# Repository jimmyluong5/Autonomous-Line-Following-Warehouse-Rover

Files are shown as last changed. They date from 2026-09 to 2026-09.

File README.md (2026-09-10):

# Multi-mode Rover
line_following_github

An autonomous line-following rover built around the **STM32G431KB**, using an 8-channel reflectance sensor array for navigation, UART for diagnostics and control, and ESP-NOW for wireless communication.

The project began as a basic motor-control prototype and has gradually evolved into a full rover platform with autonomous navigation, sensor monitoring, multiple operating modes, and wireless control.
<p align="center">
  
  
  
  
</p>

## Features

* Autonomous line following using an **STM32G431KB**
* 8-channel reflectance sensing using the **QTRX-MD-08A**
* External ADC acquisition using the **MCP3208**
* UART-based control and diagnostics through **PuTTY**
* DC motor control using **FIT0484 motors** and a **TB6612FNG dual motor driver**
* Regulated power distribution using **LM2596 buck converters**
* Wireless communication between two **ESP32-S3** modules using **ESP-NOW**
* Custom 8-bit command packet system for wireless control
* Multiple diagnostic and control modes for testing individual subsystems

## Development Process

### 1. Motor Control

The first stage of the project focused on getting the prototype working.

Two **FIT0484 DC motors** were controlled through a **TB6612FNG dual motor driver**, with the STM32G431KB acting as the main controller.

The power system uses **LM2596 buck converters** to provide regulated voltages to the motors and embedded electronics.

Once reliable bidirectional motor control was established, the prototype was mounted onto a rough cardboard chassis for early testing.

motors_github

### 2. Cardboard Prototype

A temporary cardboard rover was constructed to test the complete prototype before moving to a permanent chassis.

This prototype made it possible to verify

* Motor direction and speed control
* Wheel placement and mechanical alignment
* Breadboard wiring
* Initial sensor placement
* Basic autonomous movement

The prototype successfully demonstrated that the embedded control system and prototype could operate together before the mechanical design was finalized.

first_drive_github

### 3. Reflectance Sensor Integration and UART Sensor Calibration and Diagnostics

The next stage introduced the **QTRX-MD-08A 8-channel reflectance array** for line detection.

The sensor outputs were connected to an external **MCP3208 ADC**, allowing the STM32G431KB to acquire all eight reflectance channels in real time.

Each channel produces an analog voltage corresponding to the reflectivity of the surface underneath the sensor.

During testing

* Higher measured voltage corresponded to darker surfaces
* Lower measured voltage corresponded to lighter surfaces

The STM32 reads the MCP3208 measurements and uses the eight sensor values to determine the rover's position relative to the line.

A UART-based diagnostic interface was also created using **PuTTY** to assist with sensor calibration and subsystem testing.

The interface displays both the measured voltage and raw ADC value for each reflectance channel.

Example output

```text
--- Sensor Test Mode Active ---

CH0: 1.91V | ADC: 2376
CH1: 1.92V | ADC: 2391
CH2: 1.96V | ADC: 2442
CH3: 1.98V | ADC: 2466
CH4: 1.96V | ADC: 2434
CH5: 1.97V | ADC: 2453
CH6: 2.05V | ADC: 2552
CH7: 1.96V | ADC: 2440
```

Testing the array across different surfaces made it possible to determine usable thresholds and calibrate the line-following algorithm.

The UART interface also provides multiple operating and diagnostic modes including

* Servo control
* DC motor testing
* Reflectance voltage monitoring
* Autonomous line-following mode

This made it possible to test individual subsystems without repeatedly modifying the firmware.




### 5. Autonomous Line Following

After calibrating the reflectance sensors, autonomous line following was implemented on the STM32G431KB.

The rover continuously samples all eight channels through the MCP3208 and uses the sensor distribution to determine how far the rover has moved away from the desired path.

Motor commands are then adjusted in real time to steer the rover back toward the line.

This resulted in a complete sensing and control loop

```text
QTRX-MD-08A
      ↓
   MCP3208
      ↓
STM32G431KB
      ↓
Line-Following Logic
      ↓
  TB6612FNG
      ↓
 FIT0484 Motors
```
### 6. CAD Design

After validating the rover's electronics and autonomous navigation on the initial prototype, the mechanical components for the final rover were designed in CAD.

The CAD design focused on creating a rigid and modular platform for the drivetrain, electronics, steering system, and other mechanical components. Designing the rover as an assembly also made it possible to verify component placement, mechanical clearances, and overall dimensions before fabrication.

#### Front Steering Mechanism

The front steering assembly was designed as a separate mechanical system before being integrated into the complete rover. The mechanism allows both front wheels to steer together while maintaining a compact geometry at the front of the chassis.

The assembly was modeled in CAD to verify the movement of the steering components, wheel alignment, and clearance between moving parts.

front_assembly_zoomed

  <i>CAD model demonstrating the rover's front steering assembly.</i>
</p>

#### Main Chassis and Component Layout

The main chassis provides the structural foundation for the rover and supports the motors, wheels, electronics, power system, and cargo platform.

Component placement was considered during the design process to keep the rover compact while maintaining enough space for wiring, assembly, and access to the electrical hardware.

#### Complete Rover Assembly

After designing the individual mechanical components, they were combined into a complete CAD assembly. This allowed the overall rover geometry to be evaluated before the parts were manufactured.

The completed assembly was used to check wheel placement, steering clearance, chassis dimensions, and the positioning of the rover's electrical and mechanical components.

whole car

  <i>Complete CAD assembly of the autonomous warehouse rover.</i>
</p>

The CAD models used for the rover can be found in the [`CAD Models`](./CAD%20Models) directory.

### 7. 3D-Printed Chassis

After validating the electronics and navigation system on the cardboard prototype, the rover was transferred to a custom **3D-printed chassis**.

The chassis provides mounting for

* DC motors
* Wheels
* Breadboard and embedded electronics
* Power system
* Reflectance sensor array
* Additional mechanical components

This provided a much more rigid and repeatable platform for continued development.



### 8. Servo-Based Suspension Testing

After transferring the rover to the 3D-printed chassis, I tested a **servo-actuated front suspension system** using an SG90 servo.

The servo was used to adjust the front of the chassis and verify that the suspension mechanism could move reliably under control from the STM32.

A short demonstration clip is included below.

servo_github

The test helped validate the mechanical design before continuing with wireless control and additional rover integration.

### 9. ESP-NOW Wireless Communication

The current stage of the project focuses on wireless communication between two **ESP32-S3 modules**.

A custom command protocol is being implemented on top of **ESP-NOW**.

Button inputs on the transmitter are active-low. When a button is pressed, the corresponding command bit is set inside an **8-bit command packet**.

```text
Button Input
    ↓
GPIO Read
    ↓
8-Bit Command Packet
    ↓
ESP-NOW Transmission
    ↓
Receiver ESP32-S3
    ↓
Packet Decoding
    ↓
Command Execution
```

esp32_github

The receiving ESP32-S3 unpacks the command byte and executes actions depending on which bits are active.

Initial testing has successfully demonstrated wireless command transmission and execution using LEDs.

### 10. Wireless Button Controller Prototype

After successfully establishing ESP-NOW communication between the two ESP32-S3 modules, I built a physical **button controller prototype** to provide direct wireless input to the rover.

The controller uses an **ESP32-S3** connected to multiple push buttons. Each button represents a different rover command and is read as an active-low GPIO input.

When a button is pressed, the ESP32-S3 updates the corresponding bit in the **8-bit command packet** and transmits the packet wirelessly using ESP-NOW.

The initial controller was assembled on breadboards to allow the button layout, wiring, and firmware to be tested and modified easily.

The prototype successfully demonstrated

* Reliable detection of multiple button inputs
* Active-low GPIO input handling
* Generation of the 8-bit command packet
* ESP-NOW transmission from the handheld controller
* Wireless reception and command decoding on the second ESP32-S3
* LED-based verification of transmitted commands
* Simultaneous handling of multiple command inputs

```text
Push Buttons
     ↓
ESP32-S3 GPIO
     ↓
8-Bit Command Packet
     ↓
   ESP-NOW
     ↓
Receiver ESP32-S3
     ↓
Command Decoding
     ↓
Rover Control
```



This prototype confirms that the wireless controller architecture works as intended and provides a functional input device for the next stage of rover integration.

The next step is to connect the receiver ESP32-S3 to the rover control system so that button commands can directly control functions such as driving, operating modes, and additional rover mechanisms.

#### Current Status Update

Add the following under **Completed**

* Wireless button controller prototype
* 8-bit button command packet transmission
* Multi-button input testing

The wireless controller can now be used as the basis for full manual rover control alongside the autonomous line-following system.

### 11. Bidirectional Serial Monitoring and Wireless Command Debugging

After completing the wireless button controller prototype, I expanded the debugging interface so that both the transmitter and receiver ESP32-S3 modules can display controller activity through their respective serial connections.

On the transmitter side, button presses are detected from the active-low GPIO inputs, encoded into the 8-bit command packet, and displayed through the serial console. This makes it possible to verify that the correct command is being generated before it is transmitted wirelessly.

The packet is then sent over ESP-NOW to the receiver ESP32-S3. The receiver decodes the individual command bits and independently displays the interpreted rover command through its own serial console.

Using PuTTY, I can therefore monitor either side of the wireless connection and verify commands such as

MANUAL MODE
AUTONOMOUS MODE
INCREASING SPEED
DECREASING SPEED
STOP



The controller also supports an 8-bit speed value ranging from 0–255, with the UP and DOWN buttons adjusting the requested rover speed in approximately 5% increments.

Push Buttons
     ↓
     
Transmitter ESP32-S3
     ↓
Button Detection
     ↓
     
Serial Debug Output
     ↓
     
8-Bit Command Packet
     ↓
     
   ESP-NOW
     ↓
     
Receiver ESP32-S3
     ↓
     
Command Decoding
     ↓
     
Serial Debug Output
     ↓
     
MANUAL / AUTO / SPEED / STOP

Having serial output available on both ESP32-S3 modules provides visibility into both sides of the communication system. The transmitter output verifies that controller inputs are being correctly detected and encoded, while the receiver output verifies that the same commands are successfully transmitted, received, and decoded.

This significantly simplifies debugging because communication problems can be isolated to either the controller input stage, ESP-NOW transmission, or receiver-side command decoding.

Adobe Express - IMG_5109

The wireless controller now supports both LED-based command verification and real-time serial debugging, providing a more reliable way to confirm that ESP-NOW packets are being received and interpreted correctly.

### 12. Full Rover Integration & Multi-Subsystem Control

With the 3D-printed chassis, power distribution, and core firmware validated, the rover has progressed to a **fully integrated, multi-mode platform**. All critical subsystems are now orchestrated directly by the STM32G431KB state machine:

* **Integrated Steering & Suspension**: The front servo suspension and steering mechanism is directly integrated into the drive loop, enforcing calibrated limits (45° to 135°) with dedicated combined driving modes (front active steering + rear differential motor thrust).
* **Unified UART Telemetry & Diagnostic Interface**: An interactive, non-blocking serial dashboard allows on-the-fly mode switching between:
  * `[m]` Motor Control Mode (Differential Drive)
  * `[c]` Combined Control System (Active Steering + Rear Motors)
  * `[a]` Autonomous PID Line Following
  * `[s]` Steering Servo Calibration (45°–135°)
  * `[t]` Stepper Motor Positioning
  * `[p]` Piezo Speaker / Buzzer Frequency Testing
  * `[v]` / `[n]` Real-Time ADC Reflectance & Surface Classification

### 13. Custom ESP32-S3 Wireless Handheld Controller & Real-Time Telemetry Dashboard



The communication architecture establishes a complete, closed-loop bidirectional data link between the handheld transmitter controller, the on-rover ESP32-S3 receiver, and the main **STM32G431KB** robot brain:

```text
+------------------------------------+             +----------------------------------+             +----------------------------------+
|    Handheld ESP32-S3 Transmitter   |             |     Rover ESP32-S3 Receiver      |             |       STM32G431KB Robot MCU      |
|                                    |   ESP-NOW   |                                  |    UART1    |                                  |
| - Analog Joystick (ADC1)           | ----------> | - Decodes ESP-NOW data_packet_t  | ----------> | - LPUART1 RX (PA3): 0xAA + packet|
| - 5-Way Button Matrix (Mode/Speed) |   (2.4GHz)  | - Forwards 0xAA + packet via TX  |  (Pin 42)   | - Drives TB6612FNG Dual Motors   |
|                                    |             |                                  |             |                                  |
| - 2.4" ILI9341 Diagnostics Display | <---------- | - Forwards robot_status_t via TX | <---------- | - LPUART1 TX (PA2): 0xBB + status|
|   (Live Speeds, Ticks, RTOS stats) |   ESP-NOW   | - Captures 0xBB + status via RX  |  (Pin 2)    | - DWT Timer Benchmarks & Metrics |
+------------------------------------+             +----------------------------------+             +----------------------------------+
```

### 14. Inter-MCU UART Bridge & Hardware Verification (ESP32-S3 <-> STM32G431KB)

To complete the end-to-end communication pipeline, dedicated hardware UART communication was established and verified between the rover's on-board **ESP32-S3 Receiver** and the **STM32G431KB** microcontroller:

* **Hardware Pinout**:
  * **ESP32-S3 Pin 42 (UART1 TX)** --> **STM32 PA10 (USART1 RX / D1)** @ 115,200 baud
  * **ESP32-S3 Pin 2 (UART1 RX)** <-- **STM32 PA9 (USART1 TX / D0)** @ 115,200 baud
  * **ST-Link Debug Console**: **STM32 PA2 (TX) / PA3 (RX)** via LPUART1 @ 115,200 baud (keeps PuTTY console communication completely isolated from rover control traffic).
  * **Common Ground (GND)** connected across all modules with regulated 5V buck power distribution.

### 15. Real-Time Proportional Manual Control & Closed-Loop Wireless Driving

The manual driving implementation provides responsive, proportional throttle and differential steering mapped directly from the analog 2D joystick on the handheld controller to the rover's TB6612FNG motor driver:

* **Joystick Mixing & Proportional Control**:
  * Filtered joystick X/Y coordinates from SAR ADC1 are converted into differential drive PWM duty cycles (`0%` to `100%`) for smooth acceleration, reverse, and spot-turning.
  * Real-time deadband filtering ($\pm 25$ ADC counts) prevents unintended motor creep when the spring-centered joystick is resting at neutral.
* **Safety Watchdog & Inactivity Alarm**:
  * An integrated 5-second inactivity watchdog trips into fail-safe mode if wireless packets or user input stall, sounding an audible 8-beep alarm pattern on the piezo buzzer and automatically disarming the motors.
* **Live Return Diagnostics**:
  * The STM32 sends back 20 Hz binary telemetry frames (`0xAA + robot_status_t`) carrying live DWT superloop metrics (CPU load, latency, jitter, loop frequency) and link quality parameters directly overlaid on the 2.4" TFT LCD.

<p align="center">
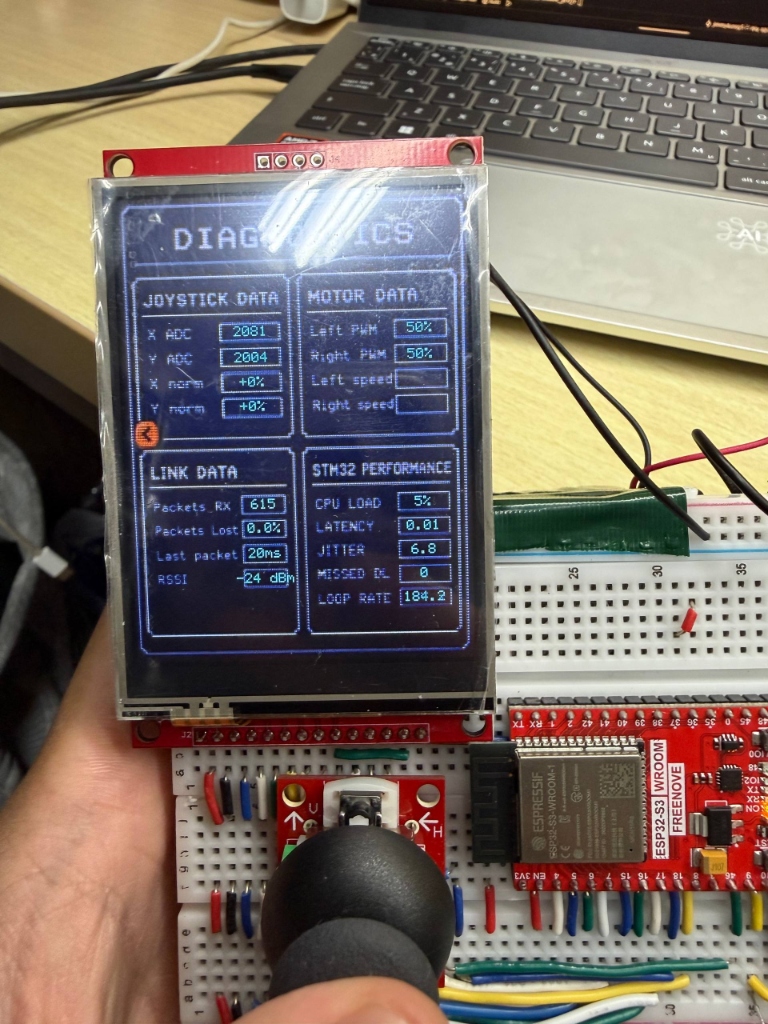
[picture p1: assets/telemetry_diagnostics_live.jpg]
Live 4-Quadrant Diagnostic Dashboard on Handheld Controller
  
  <br>
  <i>Handheld 2.4" TFT LCD displaying real-time 4-quadrant diagnostics: Live Joystick coordinates, Differential Motor PWM, ESP-NOW Link Quality, and STM32 Superloop Performance.</i>
</p>

<p align="center">
  <!-- Manual Driving Demonstration GIF -->
  Manual Rover Driving Demonstration
  <br>
  <i>Live demonstration: Real-time proportional manual joystick control and responsive wireless maneuvering.</i>
</p>

https://github.com/user-attachments/assets/510c7fbb-fd98-4aba-af33-ecc1c66d9171

## Hardware Interconnect (Receiver <-> STM32):
* **ESP32-S3 Pin 42 (UART1 TX)** --> **STM32 PA10 (USART1 RX / D1)** @ 115,200 baud
* **ESP32-S3 Pin 2 (UART1 RX)** <-- **STM32 PA9 (USART1 TX / D0)** @ 115,200 baud
* **ST-Link Debug Console**: **STM32 PA2 (TX) / PA3 (RX)** via LPUART1 @ 115,200 baud
* **Common Ground (GND)** connected across all modules with regulated 5V buck power distribution.

#### Packet Protocols:
1. **Control Packet (`0xAA + data_packet_t`)**: Transmitted at 40 Hz from transmitter to STM32, containing 5-bit tactile button masks, commanded speed (`0-255`), 12-bit analog joystick X/Y deflections, and operating mode (`Manual`, `Autonomous`, `IMU`).
2. **Telemetry Packet (`0xAA + robot_status_t`)**: Transmitted at 20 Hz from STM32 back to transmitter, delivering real-time CPU load percentage, loop rate (Hz), execution latency (ms), jitter (ms), and missed deadline counters to the controller's diagnostic UI.

To provide manual override, multi-mode switching, and live diagnostics for the rover, a dedicated handheld wireless controller was developed using a dual-core **ESP32-S3** (240 MHz) and a 2.4-inch **ILI9341 SPI TFT LCD (240×320)**.

The controller provides an interactive graphical user interface (GUI), live telemetry monitoring, and low-latency packet transmission over **ESP-NOW**.

#### 1. Hardware Architecture & Inputs
* **Microcontroller**: Freenove ESP32-S3 WROOM (16MB Flash, 8MB PSRAM, Dual Xtensa LX7 cores running at 240 MHz).
* **Display & Touch**: 2.4" 240×320 SPI LCD driven by an ILI9341 controller, sharing the SPI bus with an XPT2046 resistive touch controller.
* **Analog 2D Joystick**: Multi-sampled through SAR ADC1 (GPIO 4 and GPIO 5) with 16× oversampling, software deadband filtering, and axis normalization.
* **5-Way Tactile Button Matrix**: Multi-button input array with two-stage temporal debouncing for menu navigation, speed adjustments, and emergency stop.
* **Audio Feedback**: PWM buzzer generating audible confirmation tones on button interactions and a 5-second inactivity watchdog alarm.

```text
[ Analog Joystick (ADC1) ] ──┐
[ 5-Button Matrix (GPIO) ] ──┼──> [ ESP32-S3#1 Controller & Transmitter ] ──(ESP-NOW 2.4GHz)──> [ESP32#2 Rover Receiver ] ──(USART1 PA9/PA10)──> [ STM32G431KB ]
[ Piezo Speaker (LEDC)   ] ──┤      │ (FreeRTOS Core 0/1)                                                                                         │
[ ILI9341 240x320 LCD    ] ──┘      └──<── Live 4-Quadrant Diagnostic Telemetry Return <──────────────────────────────────────────────────────────┘
```

#### 2. Embedded Graphics Engine & Menu Animation
* **High-Speed JPEG Decoder (`tjpgd`)**: Decompresses embedded full-color JPEG assets directly from Flash memory into DMA-accessible RAM.
* **Ping-Pong SPI DMA Buffering**: Uses dual parallel line buffers to pipeline SPI transfers asynchronously while computing the next scanline on the CPU.
* **Main Menu UI**: Plays a 15-frame animated rover sequence with an active pulsing yellow hover cursor to select operating modes (**Manual Mode**, **Autonomous Mode**, **IMU Mode**).
* **Showcase Pages**: Dedicated QR code and documentation screens for GitHub and LinkedIn.

#### 3. Real-Time Manual Dashboard & 4-Quadrant Diagnostics
When entering **Manual Mode**, the controller renders an industrial diagnostic dashboard with live telemetry overlays across four dedicated quadrants:

1. **Quadrant 1: Joystick Data (Top Left)**:
   * **X / Y ADC**: 12-bit raw analog reading from SAR ADC1 (`0–4095`).
   * **X / Y norm**: Normalized deflection percentage (`-100%` to `+100%`) with center deadband filtering.
2. **Quadrant 2: Motor Data (Top Right)**:
   * **Left / Right PWM**: Real-time commanded throttle percentage dispatched to the TB6612FNG H-bridge drivers.
   * **Steering / Differential Drive**: Proportional steering mixing turning commands cleanly into left and right wheel speeds.
3. **Quadrant 3: Link Data (Bottom Left)**:
   * **Packets RX**: Total return telemetry frames successfully received.
   * **Packets Lost**: Real-time ESP-NOW packet drop rate (`0.0%`).
   * **Last packet**: Inter-packet arrival latency (`20 ms`).
   * **RSSI**: Receiver signal strength indicator in dBm (`-24 dBm`).
4. **Quadrant 4: STM32 Performance (Bottom Right)**:
   * **CPU Load**: Real-time superloop CPU utilization percentage measured by hardware DWT cycle counting.
   * **Latency**: Active loop execution latency measured to 0.01 ms precision.
   * **Jitter**: RFC 3550 exponential moving average loop jitter filter.
   * **Missed DL**: Missed loop deadline counter (execution taking >10 ms).
   * **Loop Rate**: Deterministic superloop update frequency (~184 Hz).

#### 4. Real-Time System Performance & RTOS Telemetry
To benchmark control loop determinism (comparing FreeRTOS preemptive multitasking vs bare-metal superloops), a dedicated telemetry module (`metrics.c` on ESP32 & `uart_control.c` on STM32) tracks real-time performance indicators:

| Telemetry Metric | Measurement Method | Typical Reading | Purpose |
| :--- | :--- | :--- | :--- |
| **CPU Load** | Active computation vs superloop budget | `~5–8%` | Verifies compute headroom |
| **Latency** | ARM Cortex-M4 DWT Cycle Counter (`CYCCNT`) | `0.01–0.05 ms` | Measures microcontroller active compute latency |
| **Jitter** | RFC 3550 Exponential Moving Average filter | `1.5–6.8 ms` | Tracks loop timing stability |
| **Missed DL** | Execution time exceeding 10 ms budget | `0` | Proves hard real-time scheduling guarantees |
| **Loop Rate** | Hardware period reciprocal (`1 / dt`) | `~100–185 Hz` | Confirms responsive control execution |
| **Link RSSI** | ESP-NOW WiFi MAC RX Control Metadata | `-24 to -48 dBm` | Verifies wireless link budget and antenna range |

#### 5. Wireless Communication Protocol (`ESP-NOW`) & Safety Watchdog
Control packets (`data_packet_t`) are packed into a compact binary structure and transmitted as 2.4 GHz peer-to-peer unicast packets to the receiver ESP32 on the rover:
```c
typedef struct __attribute__((packed)) {
    uint8_t  button_data;  // 5-bit tactile button mask
    uint8_t  speed;        // Commanded throttle (0–255)
    uint16_t joystick_x;   // Filtered X analog deflection
    uint16_t joystick_y;   // Filtered Y analog deflection
    uint8_t  imu_x;        // Reserved for IMU tilt control
    uint8_t  imu_y;        // Reserved for IMU tilt control
    uint8_t  mode;         // Active operating mode
} data_packet_t;
```

* **5-Second Inactivity Fail-Safe**: If no user input or joystick deflection is detected for 5 seconds in Manual Mode, the transmitter automatically triggers an audible buzzer alarm pattern (`speaker_pattern(8, 75, 75)`), trips the fail-safe state, cuts motor drive output to neutral stop, and returns safely to the main menu.

## Hardware

| Component | Purpose |
| --- | --- |
| STM32G431KB | Main rover controller |
| QTRX-MD-08A | 8-channel reflectance sensor array |
| MCP3208 | External ADC for reflectance measurements |
| FIT0484 | DC drive motors |
| TB6612FNG | Dual DC motor driver |
| ESP32-S3 ×3 | Wireless transmitter and receiver |
| LM2596 | Buck converters for voltage regulation |
| SG90 Servo | Mechanical actuation |
| LADDA Batteries | Main power source |

## Software and Communication

* Embedded C
* STM32 firmware
* UART
* SPI
* ESP-NOW
* PuTTY
* 8-bit command packet protocol

## Roadmap & Next Steps

```text
Current: Full Rover + UART Telemetry
                ↓
Phase 1: ESP32-to-STM32 Bridge & Wireless Joystick Control
                ↓
Phase 2: IMU Orientation & Heading Stabilization
                ↓
Phase 3: Time-of-Flight (ToF) Collision Detection & Auto-Braking
```

### Phase 1: ESP32-to-STM32 Bridge & Wireless Joystick Controller
* **Inter-MCU Communication**: Bridge the receiver ESP32-S3 directly to the STM32G431KB via hardware UART, forwarding decoded wireless packets into real-time drive and mode commands.
* **Analog Joystick Transmitter**: Upgrade the handheld controller with a 2-axis analog joystick to provide smooth, continuous proportional throttle and steering rather than discrete button presses.

### Phase 2: IMU Integration & Dynamic Heading Stabilization
* Integrate a 6-DOF / 9-DOF **Inertial Measurement Unit (IMU)** via I2C/SPI on the STM32.
* Implement closed-loop attitude estimation and yaw-rate compensation to maintain straight-line tracking, prevent drift, and detect chassis tilt over uneven terrain.

### Phase 3: Time-of-Flight (ToF) Collision Detection
* Integrate forward-facing **Time-of-Flight (ToF) distance sensors** (e.g., VL53L0X / VL53L1X).
* Implement real-time proximity sensing with dynamic speed reduction and autonomous emergency braking (AEB) to avoid obstacles during both manual and autonomous line-following modes.

## Current Status Summary

### Completed
- [x] Bidirectional DC motor control with TB6612FNG & dual hardware PWM (TIM1_CH1 / TIM17_CH1)
- [x] 8-Channel reflectance array acquisition via MCP3208 SPI ADC
- [x] Autonomous line-following navigation with PID control
- [x] 3D-printed chassis assembly and mechanical integration
- [x] Servo-actuated steering & suspension control (45 deg - 135 deg limits)
- [x] Multi-subsystem UART diagnostic & control dashboard
- [x] Dual ESP32-S3 ESP-NOW wireless link with binary command packet protocol (40 Hz)
- [x] Dedicated dual UART routing on STM32 (USART1 on PA9/PA10 for ESP32 receiver, LPUART1 on PA2/PA3 for PC PuTTY console)
- [x] Handheld wireless controller with 2.4" 240x320 ILI9341 LCD, 2D joystick grid, and 4 diagnostic telemetry quadrants
- [x] Real-time proportional manual joystick driving with differential throttle mixing
- [x] 5-second inactivity fail-safe timeout watchdog with multi-tone audio alarm
- [x] Closed-loop STM32 DWT performance metrics & link telemetry transmission over ESP-NOW back to handheld transmitter LCD (20 Hz)

### In Progress
- [ ] IMU sensor integration & dynamic heading stabilization (LSM6DS3 6-DoF accelerometer + gyroscope)

### Planned
- [ ] IMU-based closed-loop straight-line heading stabilization & tilt compensation
- [ ] Time-of-Flight (ToF) sensor integration for forward collision avoidance & emergency braking
- [ ] Follow-me feature using the FireBeetle 2 Board ESP32-S3 (N16R8) AIoT Microcontroller with Camera
- [ ] Return to Home Feature using dual IMUs (Adafruit LSM6DS3TR-C & MPU-6050)

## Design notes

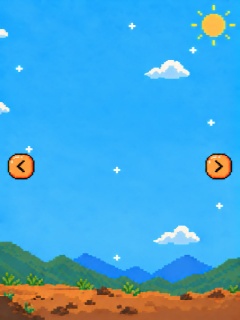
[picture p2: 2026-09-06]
esp32_transmitter/src/images/leftright.jpg

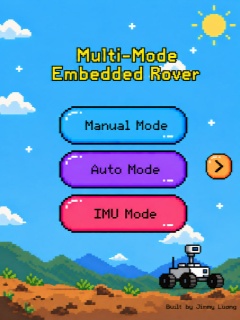
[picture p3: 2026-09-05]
esp32_transmitter/src/images/frame8.jpg

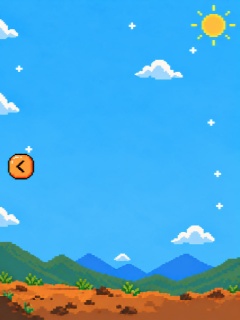
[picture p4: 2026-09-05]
esp32_transmitter/src/images/leftbasic.jpg

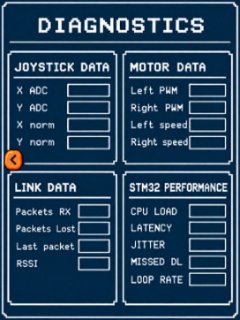
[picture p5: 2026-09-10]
esp32_transmitter/src/images/secondpagedata.jpg

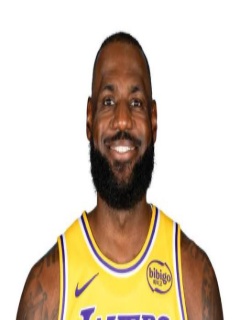
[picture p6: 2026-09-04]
esp32_transmitter/src/images/lebron.jpg

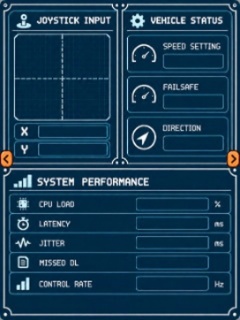
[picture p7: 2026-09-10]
esp32_transmitter/src/images/blankfirstpage.jpg

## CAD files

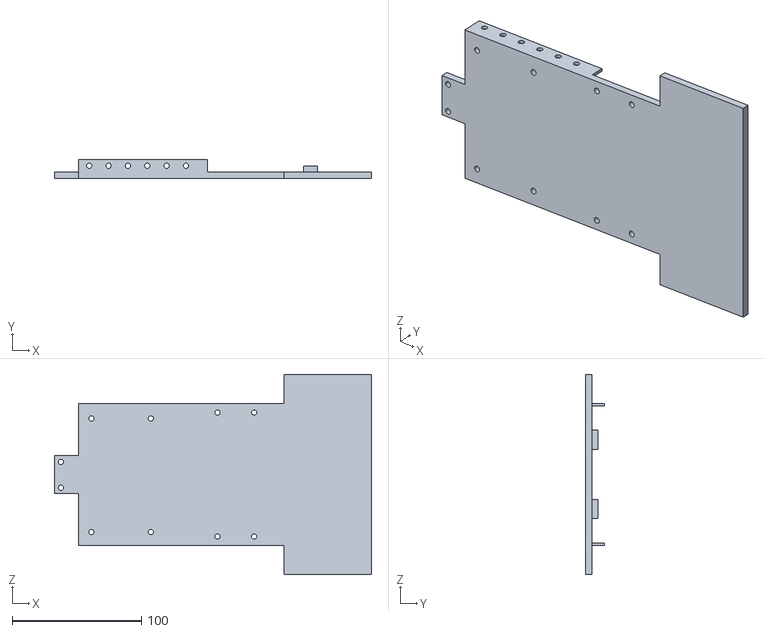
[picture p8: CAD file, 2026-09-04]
CAD Models/STL for back/main chassis-(1).STL
245.6 x 15.0 x 155.0

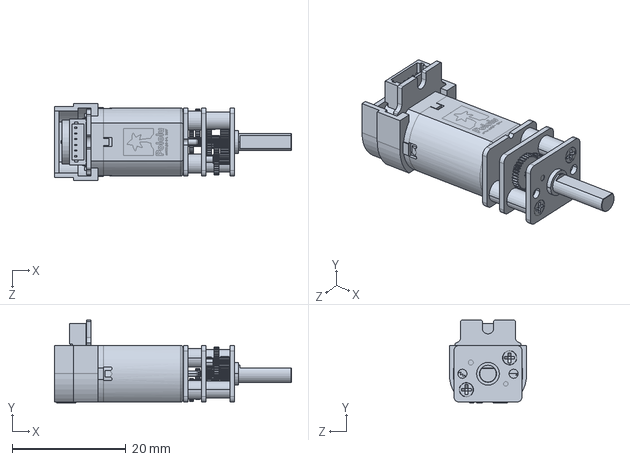
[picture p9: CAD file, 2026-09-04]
CAD Models/DC motor.SLDPRT
41.6 x 14.5 x 13.6 mm

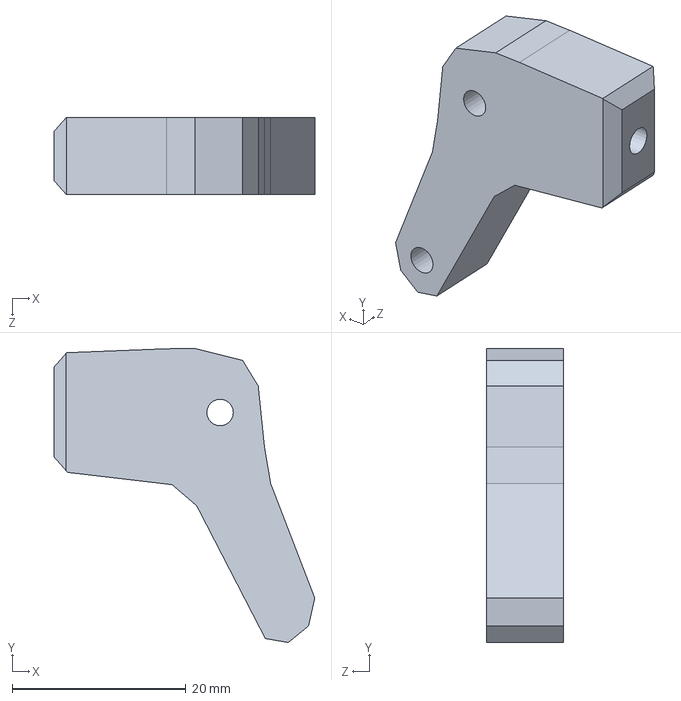
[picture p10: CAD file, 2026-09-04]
CAD Models/Front steering/L arm mirrored.SLDPRT
30.0 x 33.8 x 8.86 mm

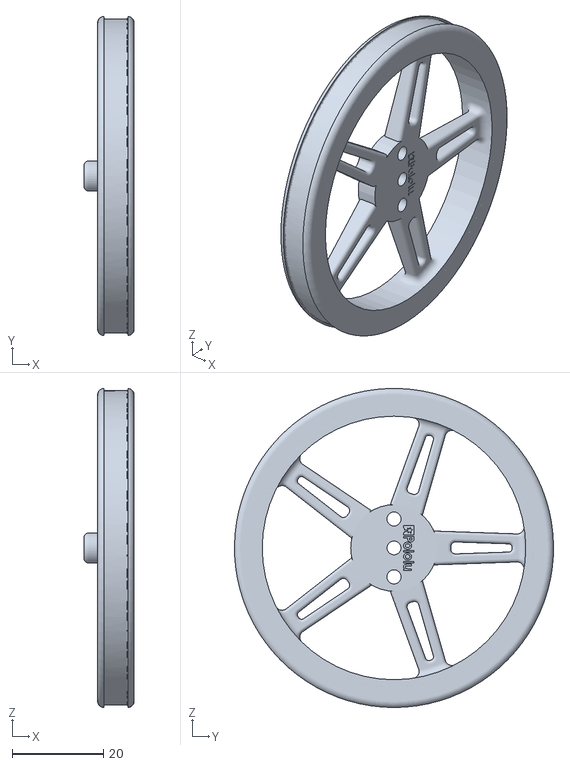
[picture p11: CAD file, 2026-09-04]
CAD Models/Front steering/STL files for front/front wheels-(2).STL
11.0 x 70.0 x 70.0

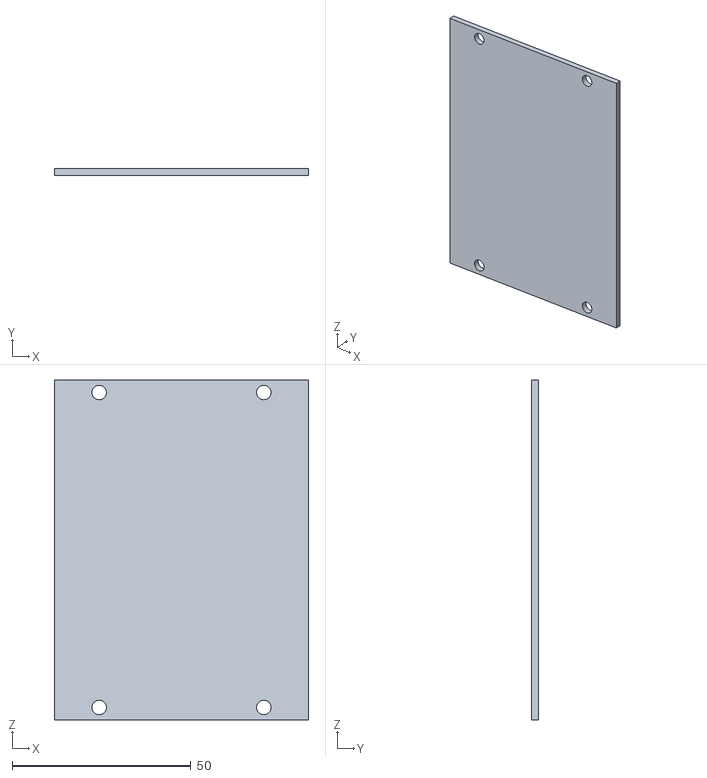
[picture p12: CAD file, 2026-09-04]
CAD Models/STL for back/sensor platform-(1).STL
71.0 x 2.00 x 95.0

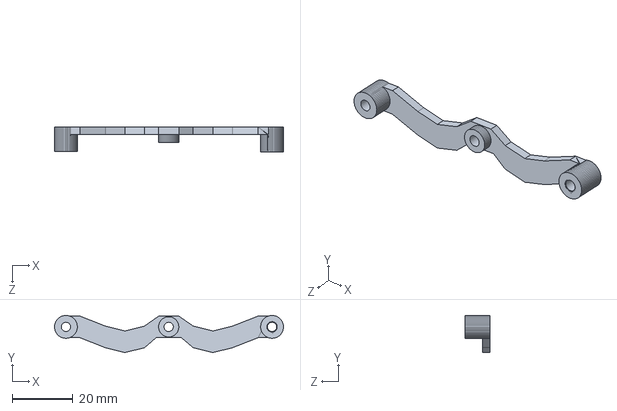
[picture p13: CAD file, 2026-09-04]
CAD Models/Front steering/linkage.SLDPRT
75.2 x 12.2 x 8.18 mm

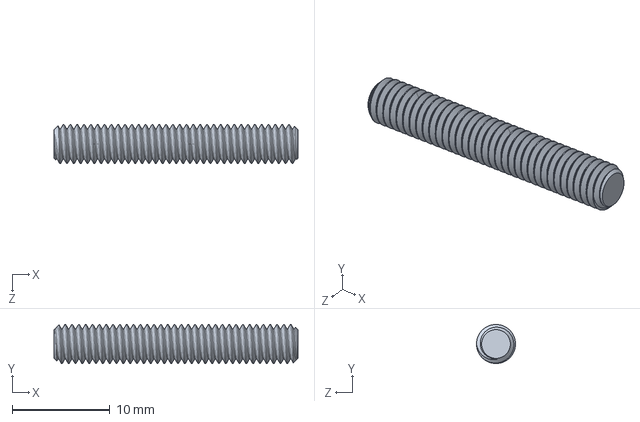
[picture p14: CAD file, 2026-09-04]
CAD Models/4x25 mm threaded rod.SLDPRT
25.0 x 4.00 x 4.00 mm

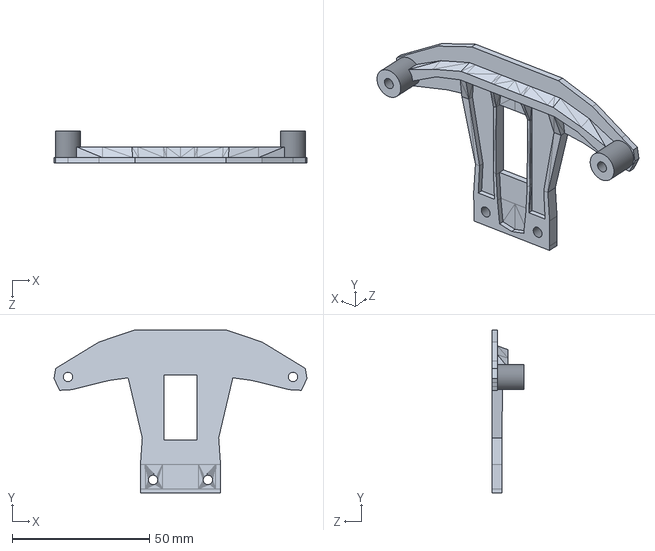
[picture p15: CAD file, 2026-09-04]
CAD Models/Front steering/Part4.SLDPRT
92.2 x 59.4 x 11.7 mm

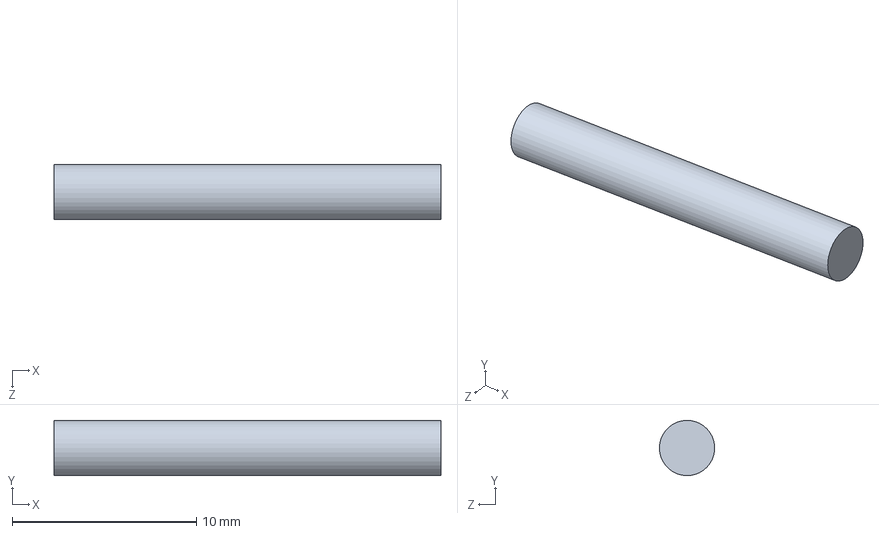
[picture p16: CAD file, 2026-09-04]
CAD Models/Front steering/21 mm rod.SLDPRT
21.0 x 3.00 x 2.99 mm

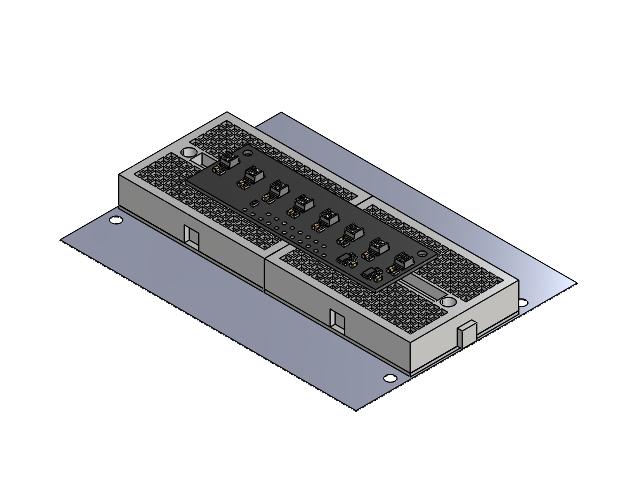
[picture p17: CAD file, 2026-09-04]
CAD Models/sensor assembly.SLDASM
ir sensor
mini breadboard x 2

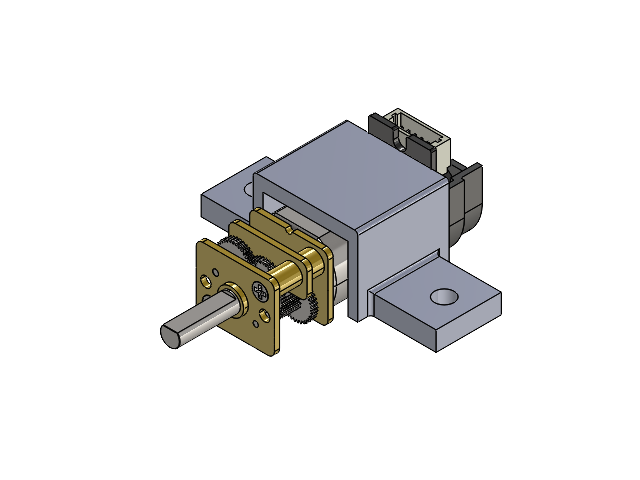
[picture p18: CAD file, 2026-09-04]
CAD Models/DC motor assembly.SLDASM
DC motor mount
DC motor

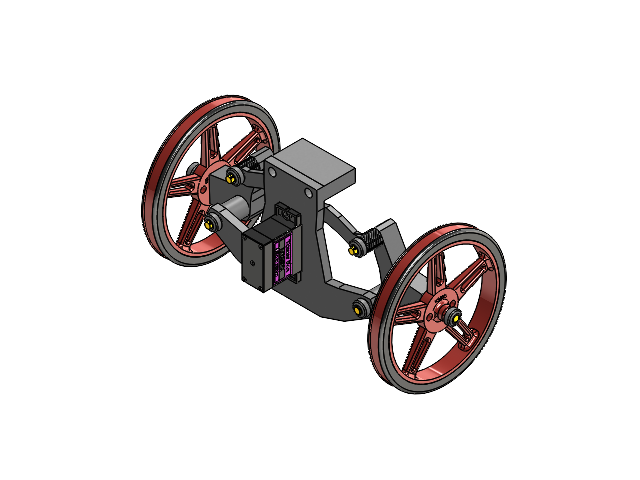
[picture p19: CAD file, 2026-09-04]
CAD Models/Front steering/front assembly.SLDASM
Tower Pro MG90S Micro servo
linkage
L arm mirrored
L arm
front wheels x 2
wheel axle x 8
Front Chassis
25 mm rod x 2
21 mm rod x 2
32 mm rod x 2
servo horn unidirectional

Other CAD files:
CAD Models/main chassis.SLDPRT
CAD Models/Front steering/STL files for front/linkage-(1).STL
CAD Models/Front steering/STL files for front/Left arm-(1).STL
CAD Models/STL for back/rear wheel-(2).STL
CAD Models/Front steering/STL files for front/right arm-(1).STL
CAD Models/sensor platform.SLDPRT
CAD Models/4x40 mm threaded rod.SLDPRT
CAD Models/7.6 cm wheel.SLDPRT
CAD Models/830 Tie Breadboard.SLDPRT
CAD Models/DC motor mount.SLDPRT
CAD Models/Front steering/25 mm rod.SLDPRT
CAD Models/Front steering/32 mm rod.SLDPRT
CAD Models/Front steering/Front Chassis.SLDPRT
CAD Models/Front steering/L arm.SLDPRT
CAD Models/Front steering/STL files for front/Front Chassis-(1).STL
CAD Models/Front steering/STL files for front/servo horn-(1).STL
CAD Models/Front steering/Tower Pro MG90S Micro servo.SLDPRT
CAD Models/Front steering/front wheels.SLDPRT
CAD Models/Front steering/servo horn.SLDPRT
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

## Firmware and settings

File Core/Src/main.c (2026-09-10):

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
/* Includes ------------------------------------------------------------------*/
#include "main.h"

/* USER CODE BEGIN Includes */
#include <motor.h>
#include <robot.h>
#include <servo.h>
//#include <stepper.h>
#include <string.h>
#include <uart_control.h>
#include "LSM6DS3.h"


/* USER CODE END Includes */


COM_InitTypeDef BspCOMInit;

SPI_HandleTypeDef hspi1;

TIM_HandleTypeDef htim1;
TIM_HandleTypeDef htim3;
TIM_HandleTypeDef htim16;
TIM_HandleTypeDef htim17;

UART_HandleTypeDef huart1;

/* USER CODE BEGIN PV */
UART_HandleTypeDef huart2;
/* USER CODE END PV */

void SystemClock_Config(void);
static void MX_GPIO_Init(void);
static void MX_TIM17_Init(void);
static void MX_SPI1_Init(void);
static void MX_TIM16_Init(void);
static void MX_TIM3_Init(void);
static void MX_TIM1_Init(void);
static void MX_USART1_UART_Init(void);
/**
  * @brief  The application entry point.
  * @retval int
  */
int main(void)
{

  /* MCU Configuration--------------------------------------------------------*/

  /* Reset of all peripherals, Initializes the Flash interface and the Systick. */
  HAL_Init();

  /* Configure the system clock */
  SystemClock_Config();

  /* Initialize all configured peripherals */
  MX_GPIO_Init();
  MX_TIM17_Init();
  MX_SPI1_Init();
  MX_TIM16_Init();
  MX_TIM3_Init();
  MX_TIM1_Init();
  MX_USART1_UART_Init();
  /* USER CODE BEGIN 2 */
  Robot_Init(); //this calls motor_init.
  servo_init();
  //stepper_init();
  DWT_Init();

  /* USER CODE END 2 */

  /* Initialize leds */
  BSP_LED_Init(LED_GREEN);

  /* Initialize COM1 port (115200, 8 bits (7-bit data + 1 stop bit), no parity */
  BspCOMInit.BaudRate   = 115200;
  BspCOMInit.WordLength = COM_WORDLENGTH_8B;
  BspCOMInit.StopBits   = COM_STOPBITS_1;
  BspCOMInit.Parity     = COM_PARITY_NONE;
  BspCOMInit.HwFlowCtl  = COM_HWCONTROL_NONE;
  if (BSP_COM_Init(COM1, &BspCOMInit) != BSP_ERROR_NONE)
  {
    Error_Handler();
  }
  huart2 = hcom_uart[COM1];
  UART_CONTROL_init();

  /* Infinite loop */
  /* USER CODE BEGIN WHILE */
  while (1) {
    uint32_t loop_start_us = DWT_GetMicros();
    Telemetry_Loop_Start();

    UART_CONTROL_update();
    UART_CONTROL_check_timeout();
    Robot_Update();
    Servo_Update();

    Telemetry_Loop_End(loop_start_us);

    static uint32_t last_telemetry_time = 0;
    if ((HAL_GetTick() - last_telemetry_time) >= 50) {
      last_telemetry_time = HAL_GetTick();
      UART_Send_Telemetry();
    }
    /* USER CODE END WHILE */

    /* USER CODE BEGIN 3 */
  }
  /* USER CODE END 3 */
}

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
/* USER CODE BEGIN Header */
/**
 ******************************************************************************
 * @file           : main.c
 * @brief          : Main program body
 ******************************************************************************
 * @attention
 *
 * Copyright (c) 2026 STMicroelectronics.
 * All rights reserved.
 *
 * This software is licensed under terms that can be found in the LICENSE file
 * in the root directory of this software component.
 * If no LICENSE file comes with this software, it is provided AS-IS.
 *
 ******************************************************************************
 */
/* USER CODE END Header */

/**
  * @}
  */

/**
  * @}
  */

/**
  * @brief  This function is executed in case of error occurrence.
  * @retval None
  */
void Error_Handler(void)
{
  /* USER CODE BEGIN Error_Handler_Debug */
  /* User can add his own implementation to report the HAL error return state */
  __disable_irq();
  __HAL_RCC_GPIOB_CLK_ENABLE();
  GPIO_InitTypeDef GPIO_InitStruct = {0};
  GPIO_InitStruct.Pin = LED2_PIN;
  GPIO_InitStruct.Mode = GPIO_MODE_OUTPUT_PP;
  GPIO_InitStruct.Pull = GPIO_NOPULL;
  GPIO_InitStruct.Speed = GPIO_SPEED_FREQ_LOW;
  HAL_GPIO_Init(LED2_GPIO_PORT, &GPIO_InitStruct);

  while (1) {
    HAL_GPIO_TogglePin(LED2_GPIO_PORT, LED2_PIN);
    for (volatile uint32_t i = 0; i < 500000; i++)
      ;
  }
  /* USER CODE END Error_Handler_Debug */
}
#ifdef USE_FULL_ASSERT
/**
  * @brief  Reports the name of the source file and the source line number
  *         where the assert_param error has occurred.
  * @param  file: pointer to the source file name
  * @param  line: assert_param error line source number
  * @retval None
  */
void assert_failed(uint8_t *file, uint32_t line)
{
  /* USER CODE BEGIN 6 */
  /* User can add his own implementation to report the file name and line
     number, ex: printf("Wrong parameters value: file %s on line %d\r\n", file,
     line) */
  /* USER CODE END 6 */
}
#endif /* USE_FULL_ASSERT */

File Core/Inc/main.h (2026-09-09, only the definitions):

#define DC_Motor_BIN2_Pin GPIO_PIN_0
#define DC_Motor_BIN2_GPIO_Port GPIOA
#define DC_Motor_BIN1_Pin GPIO_PIN_1
#define DC_Motor_BIN1_GPIO_Port GPIOA
#define DC_Motor_STBY_Pin GPIO_PIN_4
#define DC_Motor_STBY_GPIO_Port GPIOA
#define DC_Motor_AIN2_Pin GPIO_PIN_5
#define DC_Motor_AIN2_GPIO_Port GPIOA
#define DC_Motor_AIN1_Pin GPIO_PIN_6
#define DC_Motor_AIN1_GPIO_Port GPIOA
#define Motor_Driver_PWMA_Pin GPIO_PIN_7
#define Motor_Driver_PWMA_GPIO_Port GPIOA
#define Servo_Suspension_Pin GPIO_PIN_0
#define Servo_Suspension_GPIO_Port GPIOB
#define Motor_Driver_PWMB_Pin GPIO_PIN_8
#define Motor_Driver_PWMB_GPIO_Port GPIOA
#define T_SWDIO_Pin GPIO_PIN_13
#define T_SWDIO_GPIO_Port GPIOA
#define T_SWCLK_Pin GPIO_PIN_14
#define T_SWCLK_GPIO_Port GPIOA
#define ADC_SPI_CS_Pin GPIO_PIN_6
#define ADC_SPI_CS_GPIO_Port GPIOB
#define LED2_Pin GPIO_PIN_8
#define LED2_GPIO_Port GPIOB
#define ADC_CS_Pin ADC_SPI_CS_Pin
#define ADC_CS_GPIO_Port ADC_SPI_CS_GPIO_Port

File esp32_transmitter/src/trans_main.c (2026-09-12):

#include "freertos/FreeRTOS.h"
#include "freertos/task.h"
#include "setup.h"
#include "transmit_data.h"
#include "uart_control.h"
#include <stdio.h>
#include "adc.h"
#include "joystick.h"
#include "speaker.h"
#include "stdint.h"
#include <string.h>
#include "esp_log.h"
#include "math.h"
#include "lcd.h"
#include "metrics.h"
#include "stdbool.h"
#include "esp_mac.h"

#define failsafe_time 2000
bool failsafe_flag = false;

static data_packet_t last_sent_packet = {0};
uint32_t last_time_rx = 0;
void deadband_filter(data_packet_t* packet, uint16_t raw_x, uint16_t raw_y) {
 // Deadband filter
        if (abs((int)raw_x - (int)last_sent_packet.joystick_x) < 25) {
            packet->joystick_x = last_sent_packet.joystick_x;
        } 
        else {
            packet->joystick_x = raw_x;
        }
        if (abs((int)raw_y - (int)last_sent_packet.joystick_y) < 25) {
            packet->joystick_y = last_sent_packet.joystick_y;
        } 
        else {
            packet->joystick_y = raw_y;
        }
}

uint32_t last_user_active_time = 0;

void check_failsafe(data_packet_t *packet) {
    // If we're in the manual page
    if (current_page == PAGE_MANUAL || current_page == PAGE_MANUAL_DATA) {
        uint32_t now = pdTICKS_TO_MS(xTaskGetTickCount());
        
        if (last_user_active_time == 0) {
            last_user_active_time = now;
        }

        // Check if we pressed a button or the joystick moved
        int16_t jx = metrics_get_joy_x_val();
        int16_t jy = metrics_get_joy_y_val();
        bool user_active = (packet->button_data != 0 || abs(jx) > 10 || abs(jy) > 10); 
        
        if (user_active) {
            last_user_active_time = now; // Reset the inactivity timer on user input
        }

        // If 5 seconds of idle inactivity passed, trip!
        if ((now - last_user_active_time) > 5000) {
            failsafe_flag = true; 
            last_user_active_time = now;
            speaker_pattern(8, 75, 75);
            ESP_LOGW("FAILSAFE", "Inactivity timeout (5s), activating failsafe!");
            // Return to menu
            current_page = PAGE_MENU;
            active_mode = MENU_MODE;
            hovered_mode = MANUAL_MODE;
        }
    } else {
        last_user_active_time = 0;
    }
}
void app_main(void) {
    // 1. Peripherals, NVS, WiFi, LCD, UART & ESP-NOW initialization
    init_esp_nvs();
    init_wifi();
    init_esp_now();
    init_button_pin();
    init_joystick();
    init_speaker();
    init_lcd_driver();
    UART_CONTROL_init();
    

    printf("\r\n==========================================\r\n");
    printf("   ESP32 TRANSMITTER READY               \r\n");
    printf("   Pure ESP-NOW Button Transmission Ready \r\n");
    printf("==========================================\r\n");

    static uint32_t last_time = 0;
    //static uint8_t current_speed = 0;

    //eventually we will get rid of this super loop with preemptive scheduling 
    while (1)
    {
        metrics_record_loop_start(); 


        // Check for serial console commands
        UART_CONTROL_update();


        // Read joystick and buttons

        //create a clean zeroed out packet strcuture for this 10ms time frame.
        data_packet_t packet = {0};

        //print joystick debug readings to the console, not technically needed.
        print_joystick_values();


        //read the buttons first, and we sample the 5 push buttons with the debounce algo 
        packet.button_data = read_buttons();

        //call the new arrow and mode processor, then from reading the buttons we know how to process 
        //the arrow keys
        process_arrow_keys(&packet);

        //read the analog adc voltafes from the joystick.
        uint16_t raw_x = read_joystick_horizontal();
        uint16_t raw_y = read_joystick_vertical();
        


        //deadband filter.
        deadband_filter(&packet, raw_x, raw_y);

        
        packet.speed = current_speed;
        packet.mode = active_mode; //fill the mode into the packet.
        speaker_update(packet.button_data);

        // Transmit at a steady 40 Hz (every 25ms)
        uint32_t now = pdTICKS_TO_MS(xTaskGetTickCount());
        if (now - last_time >= 25) {
            last_sent_packet = packet;
            last_time = now;
            
            // Start the transmission time
            metrics_record_espnow_tx_start();
            transmit_data(receiver_mac, &packet);
        }
        //check failsafe every iteration
        check_failsafe(&packet);

        
       
        
        metrics_record_loop_end();

        //freertos non blocking delay, puts this task to sleep for 10ms, 
        //lets the cpu tackle other tasks 
        vTaskDelay(pdMS_TO_TICKS(10));  
    }
}

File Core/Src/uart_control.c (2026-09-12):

#include "robot.h"
#include <MCP3208.h>
#include <line_following.h>
#include <main.h>
#include <servo.h>
#include <stdbool.h>
#include <stdio.h>
//#include <stepper.h>
#include <string.h>
#include <uart_control.h>
#include "LSM6DS3.h"
#include <stdlib.h>
#include "motor.h"
#include "stm32g4xx_hal_uart.h"
#include <math.h>
static uint8_t current_servo_angle = 90;
//static int16_t current_stepper_angle = 0; 
// track current stepper angle starting at 0 deg.
#define BLACK_THRESHOLD 2359 // 1.90V on 3.3V ADC

extern UART_HandleTypeDef huart1; // USART1: ESP32 Receiver (PA10 RX / PA9 TX)
extern UART_HandleTypeDef huart2; // LPUART1: PC PuTTY Terminal (PA2 TX / PA3 RX)
extern SPI_HandleTypeDef hspi1;

static uint32_t last_command_time = 0;

// flag for sensor test
static bool sensor_test_active = false;

// flag for the first print in the sensor test mode.
static bool first_print = true;

// flag for the control mode
static UART_ControlMode current_mode = UART_MODE_MENU;

// declare max and min variables later to calculate the max and min of each
// channel.
static uint16_t min[8];
static uint16_t max[8];
static uint16_t filtered_adc[8];


static void UART_SendMessage(const char *message);

void menu_main(void){
  char menu_buf[768];
  int percent = (robot_speed * 100) / 999;
  snprintf(menu_buf, sizeof(menu_buf),
           "\x1b[2J\x1b[H"
           "==========================================\r\n"
           "       Warehouse Rover Control Menu\r\n"
           "==========================================\r\n"
           "Select Option/Mode:\r\n"
           " [m] - Motor Control Mode\r\n"
           " [c] - Combined Control System (Motors + Servo Steering)\r\n"
           " [v] - Voltage / IR Sensor Test Mode\r\n"
           " [b] - Both Mode (Control + Sensor Prints)\r\n"
           " [n] - Normalized Color Mode\r\n"
           " [a] - Autonomous Line Following Mode\r\n"
           " [s] - Servo Control Mode\r\n"
           " [t] - Stepper Mode \r\n"
           " [p] - Speaker/Buzzer Test Mode\r\n"
           " [i] - LSM6DS3 IMU Test Mode\r\n"
           " [u] - UART Test Mode \r\n"
           "------------------------------------------\r\n"
           "Select Speed (Current: %d%%):\r\n"
           " [1] - Set Speed to 25%% PWM\r\n"
           " [2] - Set Speed to 50%% PWM\r\n"
           " [3] - Set Speed to 75%% PWM\r\n"
           " [4] - Set Speed to 100%% PWM\r\n"
           "==========================================\r\n",
           percent);
  UART_SendMessage(menu_buf);
}

void menu_imu(void) {
  UART_SendMessage(
      "\x1b[2J\x1b[H"
      "--- LSM6DS3 IMU Test Mode Active (Mode 'i') ---\r\n"
      "Commands:\r\n"
      " [r] - Read WHO_AM_I Register\r\n"
      " [d] - Dump / Scan Sensor Registers (0x00 - 0x3F)\r\n"
      " [h] - Return to Main Menu\r\n"
      "-----------------------------------------------\r\n");
}

void menu_motor(void){
  UART_SendMessage(
            "\x1b[2J\x1b[H"
            "--- Motor Control Mode Active ---\r\n"
            "Commands:\r\n"
            " [w] - Forward\r\n"
            " [s] - Reverse\r\n"
            " [a] - Spin Turn Left\r\n"
            " [d] - Spin Turn Right\r\n"
            " [x] - Stop / Idle\r\n"
            " [f] - Force Fault\r\n"
            " [1, 2, 3, 4] - Set Speed to 25%, 50%, 75%, 100% PWM\r\n"
            " [h] - Return to Main Menu\r\n"
            "---------------------------------\r\n");
}


void menu_combined(void) {
  UART_SendMessage(
            "\x1b[2J\x1b[H"
            "--- Combined Control System Active (Mode 'c') ---\r\n"
            "Commands:\r\n"
            " [w] - Drive Forward (Servo Center)\r\n"
            " [s] - Drive Reverse (Servo Center)\r\n"
            " [a] - Steer Left (Hold for 45 deg turn)\r\n"
            " [d] - Steer Right (Hold for 135 deg turn)\r\n"
            " [x] - Stop / Idle (Servo Center)\r\n"
            " [f] - Force Fault\r\n"
            " [1, 2, 3, 4] - Set Speed (25%, 50%, 75%, 100% PWM)\r\n"
            " [h] - Return to Main Menu\r\n"
            "--------------------------------------------------\r\n");
}

void menu_speaker(void) {
  UART_SendMessage("\x1b[2J\x1b[H"
                         "--- Speaker/Buzzer Test Mode Active ---\r\n"
                         "Press keys to test:\r\n"
                         " [1] - Play continuous 1 kHz tone\r\n"
                         " [2] - Play 100ms beep\r\n"
                         " [0] - Stop sound\r\n"
                         " [h] - Return to Main Menu\r\n"
                         "---------------------------------------\r\n");
}

void menu_stepper(void) {
  // put the custom menu for stepper motor here
        UART_SendMessage("\x1b[2J\x1b[H"
                         "--- Stepper Control Mode Active ---\r\n"
                         "Controls:\r\n"
                         " [a] - Decrease angle by 5 deg (CCW)\r\n"
                         " [d] - Increase angle by 5 deg (CW)\r\n"
                         " [1] - Set to 0 deg | [2] - Set to 180 deg | [3] - "
                         "Set to 360 deg\r\n"
                         " [h] - Return to Main Menu\r\n"
                         "-----------------------------------\r\n"
                         "Current Angle:    0 degrees");
}

void menu_normalized(void) {
  // print the message.
        UART_SendMessage(
            "\x1b[2J\x1b[H"
            "--- Normalized Color Mode Active (Press 'h' to return "
            "to Main Menu) ---\r\n");
}

void menu_autonomous(void) {
  UART_SendMessage(
            "\x1b[2J\x1b[H"
            "--- Autonomous Line Following Active ---\r\n"
            "Commands:\r\n"
            " [1, 2, 3, 4] - Set Speed (25%, 50%, 75%, 100% PWM)\r\n"
            " [h]          - Stop & Return to Main Menu\r\n"
            "----------------------------------------\r\n");
}

void menu_servo(void) {
  UART_SendMessage("\x1b[2J\x1b[H"
                         "--- Servo Control Mode Active ---\r\n"
                         "Controls:\r\n"
                         " [a] - Decrease angle by 5 deg (min 45 deg)\r\n"
                         " [d] - Increase angle by 5 deg (max 135 deg)\r\n"
                         " [1] - Set to 45 deg | [2] - Set to 90 deg | [3] - Set to 135 deg\r\n"
                         " [h] - Return to Main Menu\r\n"
                         "---------------------------------\r\n"
                         "Current Angle:  90 degrees");
}

void menu_voltage(void)  {
  // print the stuff.
        UART_SendMessage("\x1b[2J\x1b[H"
                         "--- Sensor Test Mode Active (Press 'h' to return "
                         "to Main Menu) ---\r\n");
}
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

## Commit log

2026-07-13 got button pressing working
2026-07-13 uart works with button clicking
2026-07-13 got inputs from keyboard working on the led
2026-07-14 changed led button from PA0 to PA12 and began working on motor
2026-07-15 got the motors working, forward, backwards, left and right works, through putty
2026-07-15 sensor works, but not accurately
2026-07-15 just changed pin assignments, but motors and sensors work
2026-07-16 added speed control via uart, 1=25%, 2=50%.. etc
2026-07-17 just swapped forward and backwards again
    [motor.c, uart_control.c, warehouse_proj.ioc]
2026-07-18 just added a max and min for the sensor
2026-07-19 got the servo working pb0
2026-07-20 added the stepper motor stuff
2026-07-20 fixed stepper motor
2026-07-22 dont know what i added, reinstalled stm32programmer
2026-08-14 added more modes in servo mode, but fried stm32 in the process
2026-08-14 gonna work on the esp32 communication tommorrow
2026-08-15 setting up esp32
2026-08-15 got blinky to work on both boards, just gotta change the default folder each time
2026-08-16 sending data packets between esp32s
2026-08-17 trying to test servo motor with esp32
2026-08-17 got the servo movin
2026-08-17 servo works with the serial terminal
2026-08-17 trying to find the max and min degrees before the suspension system hits the servo
2026-08-20 working on the button controller
2026-08-20 finished the code for the button controller for the transmitter
2026-08-23 just testing my sv skills and the board
2026-08-23 got putty working with the button presses cuh
2026-08-23 Revise UART command monitoring details in README
    Updated README to enhance UART command monitoring section and added a new status update.
2026-08-23 changed the button outputs like text
2026-08-23 changed the buttons and included max and min speed saturations
2026-08-26 changed the button pins
2026-08-26 changed button pins
2026-08-26 changed buttons back for testing
2026-08-27 fixed led shit, wasn't even a software issue but hardware
    [led.c, rec_main.c, receive_data.c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]
2026-08-27 fixed led shit
2026-08-27 adding led for the transmitter
2026-08-27 added the led feature for the button clicking for transmitter
2026-08-27 working on configuring adc then joystick
2026-08-28 speaker works, gonna work on the button debouncing
2026-08-28 the buttons and the joystick click works for making noise
    [joystick.c, speaker.c, trans_main.c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]
2026-08-28 added button displaying putty
2026-08-28 added a lot of stuffor the buttons to show to putty
2026-08-28 changed the frequency of the buttons
2026-08-28 things are working, next is sending the data via uart to the stm32, but i need to do the car steering first with the servo
2026-08-29 testing my stm32 again
2026-08-29 added servo suspension system
2026-08-29 saving shit, tryna integrate the servo and the motor together
2026-08-29 swapped left and right for the servo, and the controlling actually works
    [robot.c, servo.c, servo.h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]
2026-08-31 cleaning up code in the uart control file
2026-09-01 added imu and testing encoders again
2026-09-01 encoders work again
2026-09-01 removed the button leds, trying to free pins for screen
2026-09-03 3D Models
    [21 mm rod.SLDPRT, 25 mm rod.SLDPRT, 32 mm rod.SLDPRT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]
2026-09-03 Main body
    [4x25 mm threaded rod.SLDPRT, 4x40 mm threaded rod.SLDPRT, 7.6 cm wheel.SLDPRT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]
2026-09-03 Revise README with CAD design and testing updates
    Updated the README to include detailed sections on CAD design, 3D-printed chassis, and various testing phases. Renumbered sections for clarity and improved organization.
2026-09-04 removed servo, then worked on the screen
2026-09-04 fixed that wavy shit
    [lcd.c, pretty_effect.c]
2026-09-05 the animations work
    [partitions.csv]
2026-09-06 docs: add section 13 for ESP32-S3 wireless controller and telemetry dashboard
2026-09-07 setting up uart here
2026-09-07 finished setting up uart for the stm32 and the function to send the data
2026-09-08 bruh all i needed to do was use different uart pins and it would've worked
2026-09-08 feat: complete bidirectional UART bridge (ESP32 <-> STM32) and update README
2026-09-08 docs: add Part 14 to README with UART verification screenshot
2026-09-08 got the uart communication working between the receiver and the stm32, bruh just needed to change the pins the whole time
2026-09-09 added uart mode
2026-09-09 reomved the encoders and changed the pwmb pin
2026-09-09 removed encoder stuff and the uart communication works
2026-09-09 removed encoders in transmitter
2026-09-09 removed anything related to encoders, will need to update both pages on manual mode
2026-09-10 adding failsafe in case we don't send any packets to the robot
2026-09-10 added the failsafe telemetry display and the alarm
    [pretty_effect.c, speaker.c, trans_main.c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]
2026-09-10 added failsafe, so if you don't send a command for 5 seconds it trips
    [setup.c, speaker.c, trans_main.c]
2026-09-10 replaced the encoder shit with the stm32 other shit
    [pretty_effect.c, setup.c]
2026-09-10 just changed the struct the stm32 is going to send
2026-09-10 changed the struct that the stm32 is going to send
2026-09-10 the stm32 sending data works
2026-09-11 understanding dma and ping pong buffer
2026-09-12 determining max and min servo values again
